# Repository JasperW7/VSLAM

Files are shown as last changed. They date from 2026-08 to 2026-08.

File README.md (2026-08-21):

## For HackClub Macondo
*This repo is forked off of the official FTC SDK & Pedro Pathing

*Heavy inspiration from https://learnopencv.com/monocular-slam-in-python/
### Monocular VSLAM Turret
I was slightly involved in a project a while back focusing on drones and the use of camera vision for mapping over something like a laser used for rangefinding. I got interested in the idea of visual simultaneous localization & mapping (VSLAM) and how it could be integrated into drone navigation systems. My vision for this project was to mainly test out the system flow & software behind a single camera VSLAM (monocular), less so about the automation and navigation. Another challenge I wanted to tackle was configuring monocular VSLAM using a cheap and affordable webcam with low processing power.

### Finished product
Currently, the product is able to use OpenCV to return a camera stream back to Panels stream for viewing, as well as displaying the bot's pose in field coordinates (also viewable under Panels Field).
### Build
All STL Files can be found under [STL Folder](https://github.com/JasperW7/VSLAM/tree/main/STL) with a viewable [Onshape](https://cad.onshape.com/documents/fbfda43b3c9a34854064ec10/w/3fedeb5aa6c3b0ad226559e0/e/34f30c8dd9f021da3e9b9f1b)
You will need:
- wheel x2
- frame x1
- camera holder x1
- gears (2) x1
- pulleys (2) x1
  
The build was designed mainly around M3 screws, and the control system revolves around a [Rev Control Hub](https://www.revrobotics.com/rev-31-1595/), 12V battery (xt30 end), 4 standard 25T PWM servos, 25T servo horns, 64T belt, and a [C270 Logitech webcam]( https://www.logitech.com/en-ca/shop/p/c270-hd-webcam).
For the sake of time, we printed our own [688 bearings](https://grabcad.com/library/688-bearing-8x16x5mm-1), however metal 688 bearings will work as well.

For assembly, simply attach the servos to the frame & gears with screws, then mount the wheels after. This avoids the wheels from blocking the screw mounting for the servos. 
Next, attach the bearings into the frame and big gear holders (we used super glue). You can attach the big gear to the frame and the camera holder into the holders now. Attach the pulley to the tilt servo with a belt running across the pulleys.
Finally, remove the stock c270 mount from the webcam and slide the isolated webcam into the camera holder.
Wire the servos to ports 0,1,2, and 3, plug in the webcam usb to the USB port on the control hub and connect the battery to power it up. [Wiring Diagram](https://github.com/JasperW7/VSLAM/blob/main/Wiring%20Diagram.png)


### Software
To get started with software, simply install Android Studio and clone this repository. To upload this repository onto the control hub, simply connect a usb c to the control hub port and click on the "Run TeamCode" button. Another option is to install the ADB Wifi plugin and connect to the control hub wifi to push code. 

To access the Panels Dashboard, connect to the robot wifi and head to http://192.168.43.1:8001/ on your browser. For setup, under the Teleop dropdown, select the calibration opmode. You will need to print out the following checkerboard pattern used for OpenCV's checkerboard calibration: https://github.com/opencv/opencv/blob/4.x/doc/pattern.png. Run the opmode and select widgets under the Panels Dashboard for Camera Stream. Ensure that the webcam is able to see the checkerboard and move the camera around (you can use the pan and tilt servos for this or you can move the camera manually). The calibration will select 20 points and return calibration values (fx, fy, etc.) to telemetry. Hold onto these values.

Finally, you can run the "test vslam" opmode. Under configurable variables, plug in the fx, fy, cx, cy, k1, etc. calibrated values. The defaults in there are the values that worked for me. Under Panel's camera stream, there should be points plotted by OpenCV's ORB feature extraction. For mapping, simply add a widget for the Panels Field. On top of the field drawing, there will be lines displayed for the camera's pose.
 
___
## Day-by-day journal entries (Failures, Thoughts, etc.) [https://docs.google.com/document/d/1HC7wofTFJbAAgc9IIZ6yAzwW5cy-wWwRABX2THkkn_8/edit?tab=t.0]

Aug 2

Our vision for this project is to learn and utilize Visual Simultaneous Localization & Mapping (VSLAM) using a single cheap and affordable webcam. Our goal is to have a fully autonomous 2 degree of freedom camera scan the full area in 3-d space and map out the environment accurately. 

Today, we focused on planning out our design and taking inventory of the parts we had available. For our project, we wanted to incorporate multiple subsystems that worked together, namely a 2-wheel drive base, a 2DOF turret and a camera. 

In our first sketch, we discussed how our robot would behave in the environment. For example, our initial idea was to only include a panning turret, however we decided that we wanted to have a robot that was able to drive around and a secondary tilt in addition to the panning. We drew rough ideas of how these mechanisms would interact with each other, such as the tilt servo driving a belt that controls the shaft that the camera is mounted onto.

After our rough draft, we spent some time detailing our drawing to define the major parts of the build. Notably this includes the implementation of our servos and how we plan for them to provide the 2 axis of rotation. This allows us to more thoroughly visualize the project before we begin our CAD.

Aug 2 

With a general idea of the direction we were headed, we began CADing on OnShape. While I (Jasper) imported the CAD of the REV servo and generated the gears, Bowen began modeling the servo mount/frame. 

We wanted as many parts of our robot to be as 3d-printable as possible, however, one issue we encountered was the possibility of printing servo horns. Since the spline was too fine, we opted for buying aluminum horns. One issue we faced was finding online STL/Step files that were available to match the online listings so that we could accurately place them into our CAD. We worried that if a cad didn’t match, parts wouldn’t mesh properly. Eventually, we found a proper step file and based all of the servo attachments such as the wheels and gears off of it.

Designing the servo mount was relatively smooth as it was just the projection of the servos’ outline to create holes. 2 mounts were created vertically for the wheels and one was created horizontally on the surface of the mount for the camera’s panning. We had to tweak the positioning of the servo as initially we wished for the servo to be placed vertically (shown in the following picture), though it ended up taking too much space. This was not a difficult change fortunately as we just rolled back a couple edits and recreated the necessary holes.

Another issue we forgot to account for was the existence of the control system. We forgot to incorporate the control hub and battery into our original sketch, and since we wanted the profile of the robot to be as small as possible, another challenge was fitting the control system in without taking up too much space. We found that the space between the wheel servos was enough to fit the control hub and we could still attach the battery underneath as long as we extended the frame. We intend to add a balancing ball at the bottom to keep the battery from touching the ground. 

Aug 3 

With the foundation of the bot finished, today we aim to model the camera mount and the pulley system that will control the camera’s tilt. Going off of our sketch, we had a few major parts to CAD. The large gear has to be modified with handles that support the shaft and pulley system (Jasper). A hex shaft also has to be made with an integrated mount which will ultimately hold the camera (Bowen).

Handles

The handles were relatively smooth to CAD. Just 2 extrusions on the gear with a rounded top so the camera clears it when looking up and down. Going into this project, we wanted to create this robot without the need for funding by using spare parts we already own. Jasper already has a pulley system of 2 gears and a belt (we may just union the gear on the shaft to the shaft itself to print as one part, but we’ll consider that later). The belt he has is 64 teeth, which caused some issues in the modeling of the handles as we needed to continually increase the height of them to accommodate for its length. This was also necessary as the camera must sit high enough to capture the floor in its FOV without being blocked by the chassis. Additionally, a slot for our fourth and final servo that will be spinning the servo.

Shaft/Camera Mount

The shaft went through a couple iterations in its design as the cameras’ hinges and dimensions were a tad finicky. I (Bowen) initially created the shaft to be a cylinder rather than a hex shaft. This was not very practical as there needs to be as much friction as possible for it to move with the bearing. 

We are using a logitech camera that has this mounting hole on the back:

So I initially designed the axle to have a horn that threads through the hole to support the camera vertically (1).  This small horn was very brittle and would’ve likely snapped due to the weight of the camera or the motion of the pulley. As such, I added a back to the horn that would help to hold up the camera. While I was designing this, it was about the time when Jasper imported the CAD for his pulley and mated it onto our existing model. It was then that I noticed the camera indeed clipped into the pulley as I didn’t expect the pulley to be so large (2). This is why we ended up rotating the camera, placing it horizontally to help it clear the pulley. I then restarted the design for my axle to account for this, making sure the lens itself was still centered and the camera protruded enough to clear the pulley (3).

Since most of the CAD was near completion, we decided to go through and check if there were any failure points that could occur, including checking how wires would route and fasteners. 

We decided to perform voronoi pocketing on the frame to create holes where we could zip tie extra lengths of wire so they wouldn’t drag on the ground. This came with the extra benefit of aesthetics as well while not being damaging to structural integrity. 

Another problem we realized was that the servo we were using for panning the gears was blocking the USB port on the control hub, meaning the camera wouldn’t be able to connect to the control system. Because of this, we rotated the servo around the spline 180 degrees to instead block the HDMI port. We also added in the balancing ball point underneath the battery box to hold it up against the ground. We figured that a point round surface scraping the ground would be better than an entire flat surface against the ground. 

Finally, after much review, we sent the necessary CAD pieces off to print (while we go out to buy fasteners). 

We also started looking into an article about the algorithm behind monocular VSLAM and understanding how it works, previewing ourselves for when we get into the software side.

We looked inside multiple hardware stores for M3 screws but couldn’t find any. Nonetheless, we decided to first stop and test the controller we would use to control the robot. We wanted to test the controllers connection to the driver station APK and ensure that it would work. 

One issue we found was that we couldn’t directly connect the controller straight to the phone with a usb c to c wire. For connections, the controller would only return values through a usb A wire. Therefore, we bought an adapter to go from usb c to usb a to usb c :). This worked :).

We picked up the parts for our control system including the control hub, adapter wire and logitech c270 webcam that we would be using. (We were also going to pickup our CAD prints too but the print layer shifted so we restarted the print). 

One thing we noticed when we tested the battery to wire converter to control hub power was the connection was iffy. If the wire was bent the wrong way, the power would disconnect. Seeing as the power had to go through a tamiya connector and then to an xt30 connector, we imagined that the tamiya connection was a potential failure point. So, we cut off the tamiya connection and soldered the xt30 head straight to the wire.

While soldering, we had trouble getting the solder wire to flow through the wire. We thought flux would allow it to flow better, but even with flux, the solder wire just wouldn’t flow. This is when we realized that better solder wire is more advantageous than just good flux alone. The solder wire we got was bought cheap online, which explains why it wouldn’t flow properly. Even so, after soldering, our wire passed the pull test so we figured it would hold up. 

We tested it by connecting it to the control hub and it wouldn’t power on. We thought it was a soldering mistake again so we re-soldered the joint. After the second attempt was finished, it still wouldn’t power on. This is when we realized that the fuse that is inside the battery wire had been blown out. Once we swapped the fuse, it powered up.

## **Assembly**

Though the battery can connect to the control hub, we forgot the charging wire connected through the tamiya head. As such, we had to spend some time soldering an adapter that connects the battery’s xt30 back to the tamiya to be able to charge.

### Bearings
As the prints were finished we began to assemble the chassis. We ran into a couple issues with the bearings and the shafts they were supposed to hold. It seems that the tolerance for the shaft was incorrectly done. It took a lot of force to get the shaft into the bearing. In doing so we broke the axle under the big gear.

After it superglues back on, we’ll sand or file it down so it cleanly fits into the bearing. The camera shaft has a similar issue, but we got it in eventually. All the holes for the bearings were a bit too large and made them loose, though it's not much of an issue as we can use superglue to keep them in place.

## Camera Mount
The shaft that holds the camera also did not fit the camera in real life. More specifically the backing that was supposed to hold the camera ended up being so long that the rod in the middle could not be threaded into the hole in the middle. We had to cut off a bit of the edge which allowed the camera to fit.



## Battery holder
A similar thing happened with the battery holder. The battery was bigger in real life, so we just cut off a side of the holder to help it squeeze in.



## Pulley Installation of Doom
There were many issues with the pulley installation. Aside from the bearings not fitting the shaft perfectly, we forgot to put the belt in before we put the axle on. So we had to remove the already stuck and glued bearings and put the belt in. Then we realised the shaft itself was put on the wrong way (not on the side of the servo), so we had to take everything off AGAIN and flip it. Yikes!

The screws we used to connect the wheels to the servo were too long, so we cut them to size.



## Axle on the Big Gear
Back to the axle on the big gear that snapped off when we tried forcing the bearing in. The superglue was taking a while to dry, so we put a bit of water around it. For some reason it turned white and still didn’t dry. Not sure how we’re going to deal with this but I hope it’ll just dry eventually.



Here's some final pictures of our progress today:


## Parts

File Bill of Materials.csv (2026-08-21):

Type | Link | Part number/SKU | Item | Quantity | Price
3d print | N/A | N/A | Frame | 1 | $0
3d print | N/A | N/A | Small gear | 1 | $0
3d print | N/A | N/A | Big gear | 1 | $0
3d print | N/A | N/A | Pulley | 1 | $0
3d print | N/A | N/A | Camera holder | 1 | $0
3d print | N/A | N/A | Wheel | 2 | $0
3d print | N/A | N/A | 688 bearings | 3 | $0
Control system | https://revrobotics.ca/rev-31-1595/ | REV-31-1595 | Control hub | 1 | $525.00
Control system | https://www.studica.ca/en/txm-12-volt-rechargeable-nimh-battery-pack | 39057 | Battery | 1 | $92.00
Control system | https://www.studica.ca/en/xt30-mh-fc-to-tamiya-mh-fc-cable | 70179 | Tamiya to XT30 adapter | 1 | $5.73
Control system | https://revrobotics.ca/rev-41-1097/ | REV-41-1097 | Servo | 4 | $34.42
Control system | https://www.amazon.ca/Logitech-Widescreen-Calling-Recording-960-000694/dp/B004FHO5Y6?th=1 |  | Logitech C270 webcam | 1 | $27.96
Control system | https://www.gobilda.com/3412-series-5mm-htd-pitch-timing-belt-9mm-width-320mm-pitch-length-64-tooth/ | 3412-0009-0320 | 64T HTD5 belt | 1 | $7.56
Fastener | https://www.amazon.ca/Kozelo-440pcs-Socket-Screws-Assortment/dp/B0DK5ZMMY6 |  | M3 screw 30mm | 4 | $24.79
Fastener |  |  | M3 screw 20mm | 8
Fastener |  |  | M4 screw 12mm | 8
Fastener |  |  | M3 nyloc nut | 6
Fastener |  |  | M4 nyloc nut | 8
Fastener | https://www.amazon.ca/dp/B0F5QDX7PN?ref=ppx_yo2ov_dt_b_fed_asin_title |  | 25T servo horn | 4 | $12.99

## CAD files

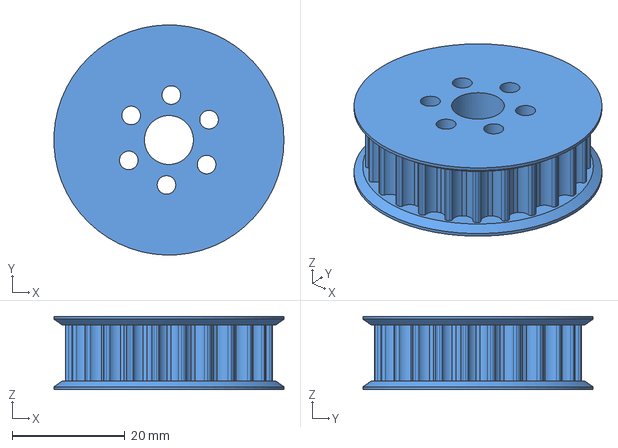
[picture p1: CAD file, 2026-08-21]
CAD/STEP/Assembly 1 - [LS] Pulley HTD5 24T.step
40.9 x 40.9 x 13.0 mm

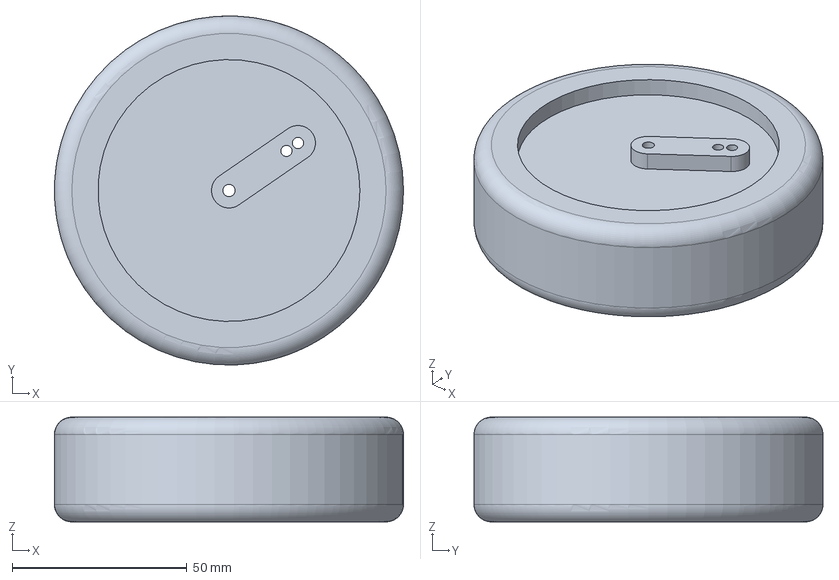
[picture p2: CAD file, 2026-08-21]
CAD/STEP/Assembly 1 - wheel.step
100.0 x 100.0 x 30.0 mm

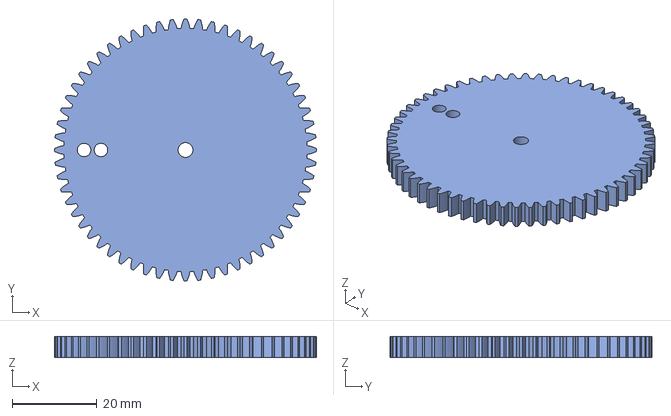
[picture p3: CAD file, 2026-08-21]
CAD/STEP/Assembly 1 - Spur 1M 60T.step
62.0 x 62.0 x 5.00 mm

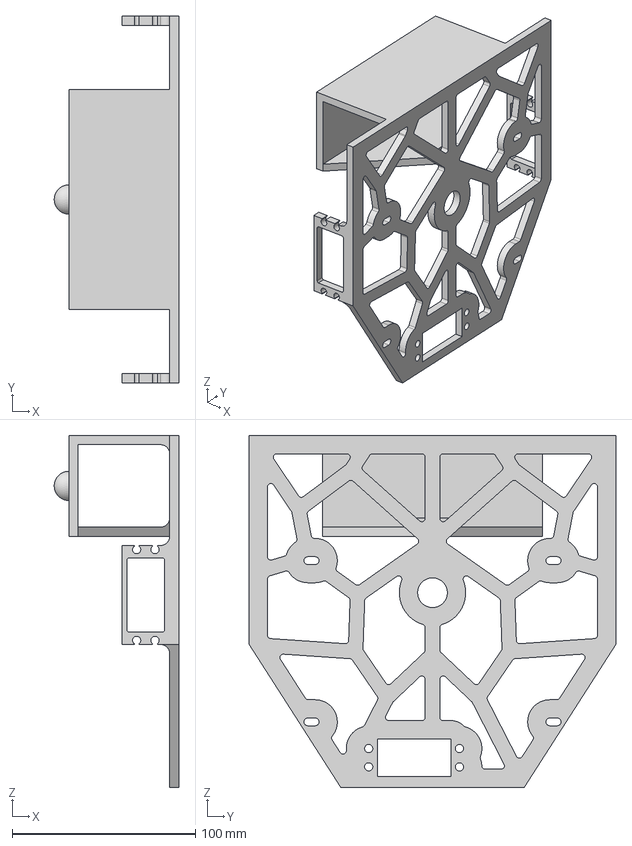
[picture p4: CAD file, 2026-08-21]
CAD/STEP/Assembly 1 - frame.step
68.0 x 200.0 x 192.0 mm

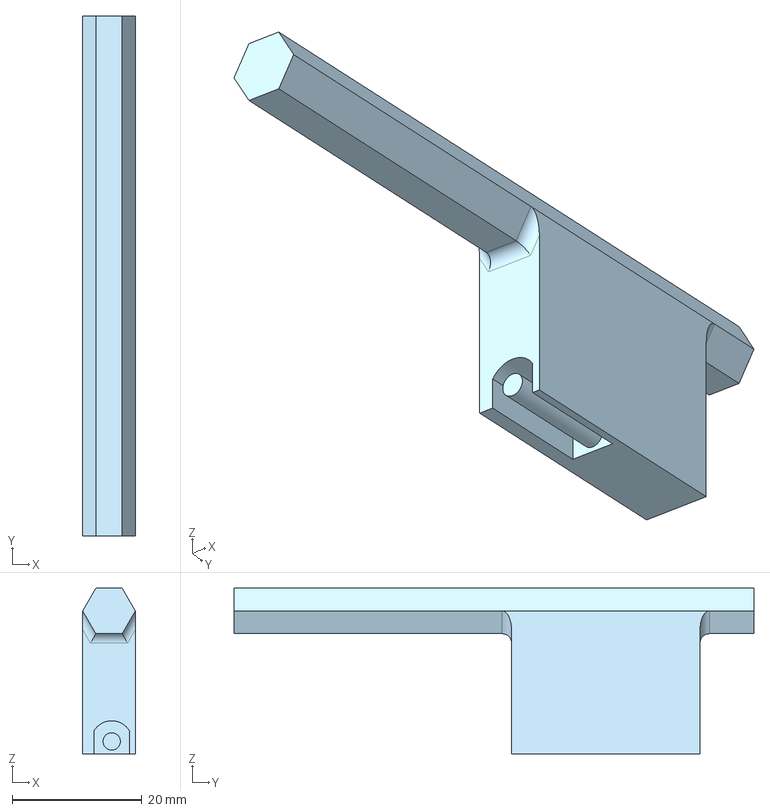
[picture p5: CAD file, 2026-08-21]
CAD/STEP/Assembly 1 - camera holder.step
8.10 x 80.0 x 25.5 mm

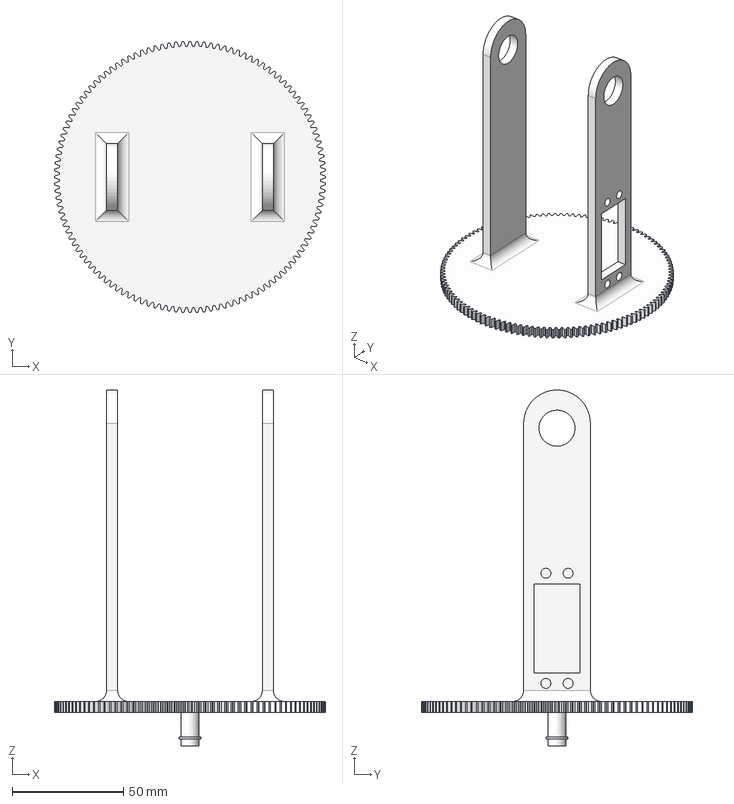
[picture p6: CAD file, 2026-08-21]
CAD/STEP/Assembly 1 - Spur 1M 120T.step
122.0 x 122.0 x 160.0 mm

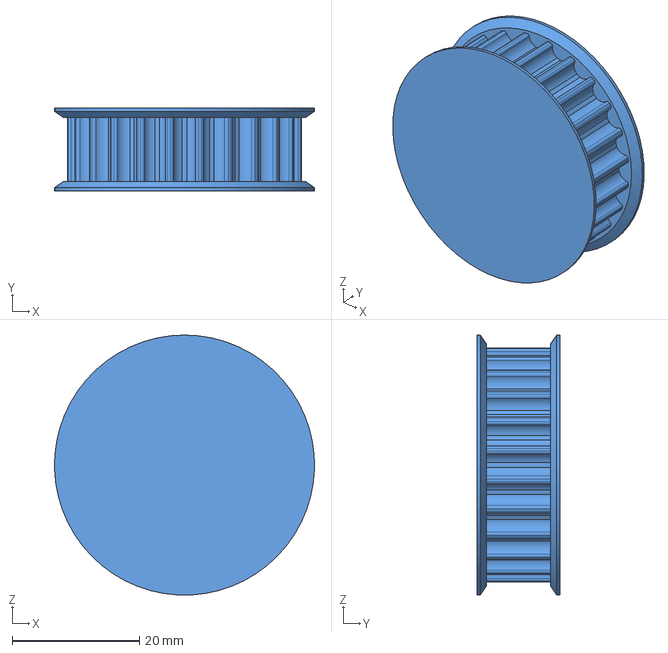
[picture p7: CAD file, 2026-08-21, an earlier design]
CAD/STEP/Assembly 1 - [LS] Pulley HTD5 24T (1).step
40.9 x 13.0 x 40.9 mm

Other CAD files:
CAD/STL/Assembly 1 - Spur 1M 120T.stl
CAD/STL/Assembly 1 - Spur 1M 60T.stl
CAD/STL/Assembly 1 - [LS] Pulley HTD5 24T (1).stl
CAD/STL/Assembly 1 - [LS] Pulley HTD5 24T.stl
CAD/STL/Assembly 1 - camera holder.stl
CAD/STL/Assembly 1 - frame.stl
CAD/STL/Assembly 1 - wheel.stl

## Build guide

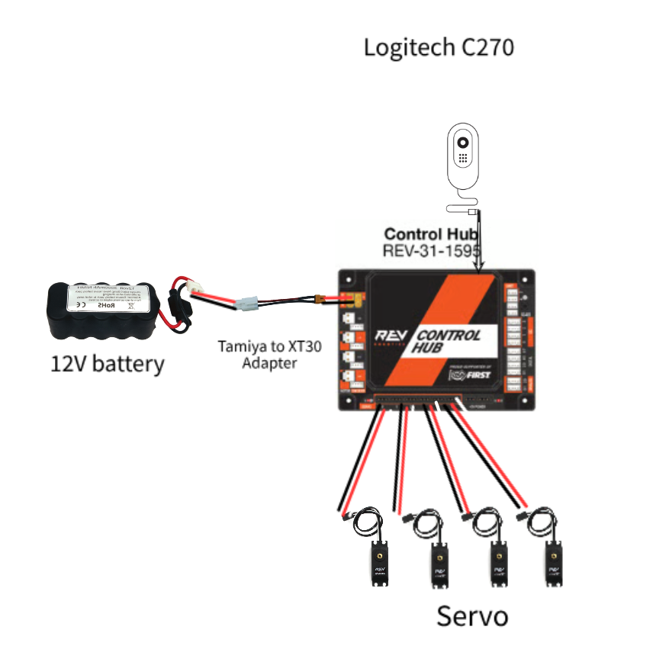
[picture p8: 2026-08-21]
Wiring Diagram.png

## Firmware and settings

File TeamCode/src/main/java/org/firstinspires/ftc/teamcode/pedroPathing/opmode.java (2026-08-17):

package org.firstinspires.ftc.teamcode.pedroPathing;

import android.graphics.Bitmap;
import android.graphics.Canvas;

import com.acmerobotics.dashboard.config.Config;
import com.bylazar.camerastream.PanelsCameraStream;
import com.bylazar.configurables.annotations.Configurable;
import com.bylazar.telemetry.PanelsTelemetry;
import com.bylazar.telemetry.TelemetryManager;
import com.qualcomm.robotcore.eventloop.opmode.OpMode;
import com.qualcomm.robotcore.eventloop.opmode.TeleOp;
import com.qualcomm.robotcore.hardware.Servo;

import org.firstinspires.ftc.robotcore.external.function.Consumer;
import org.firstinspires.ftc.robotcore.external.function.Continuation;
import org.firstinspires.ftc.robotcore.external.hardware.camera.Camera;
import org.firstinspires.ftc.robotcore.external.hardware.camera.WebcamName;
import org.firstinspires.ftc.robotcore.external.stream.CameraStreamSource;
import org.opencv.core.Point;
import org.opencv.core.Scalar;
import org.opencv.imgproc.Imgproc;
import org.openftc.easyopencv.OpenCvCamera;
import org.openftc.easyopencv.OpenCvCameraFactory;
import org.openftc.easyopencv.OpenCvCameraRotation;
import org.openftc.easyopencv.OpenCvPipeline;
import org.opencv.android.Utils;
import org.opencv.core.Mat;
import org.opencv.core.MatOfPoint2f;
import org.opencv.core.MatOfPoint3f;
import org.opencv.core.MatOfDMatch;
import org.opencv.core.DMatch;
import org.opencv.core.CvType;
import org.opencv.calib3d.Calib3d;
import java.util.ArrayList;
import java.util.List;
import java.util.concurrent.atomic.AtomicReference;
@Configurable
@TeleOp(name="VSLAM")
public class opmode extends OpMode {
    Servo wheel1,wheel2,pan,tilt;
    OpenCvCamera webcam;
    TelemetryManager.TelemetryWrapper panelsTelemetry;
    CameraStreamSource source;
    public static double wheel1Pos=0.5,wheel2Pos=0.5,panPos=0.5,tiltPos=0.3;
    public static double brightnessTolerance = 0.2;
    public static int consecutiveBrightnessTol = 11;
    public static double matchRatio = 0.7;
    public static int maxDescriptorDistance = 2500;
    public static int ransacInt = 30;
    public static double ransacThresh = 5;

    public static ArrayList<Feature> features = new ArrayList<>();
    public static ArrayList<Match> matches = new ArrayList<>();
    @Override
    public void init() {
        wheel1 = hardwareMap.get(Servo.class,"wheel1");
        wheel2 = hardwareMap.get(Servo.class,"wheel2");
        pan = hardwareMap.get(Servo.class,"pan");
        tilt = hardwareMap.get(Servo.class,"tilt");
        panelsTelemetry = PanelsTelemetry.INSTANCE.getFtcTelemetry();

        int cameraMonitorViewId = hardwareMap.appContext.getResources().getIdentifier("cameraMonitorViewId","id",hardwareMap.appContext.getPackageName());
        WebcamName webcamName = hardwareMap.get(WebcamName.class,"c270");
        webcam = OpenCvCameraFactory.getInstance().createWebcam(webcamName,cameraMonitorViewId);
        CameraPipeline pipeline = new CameraPipeline();

        webcam.setPipeline(pipeline);
        source = pipeline;

        webcam.openCameraDeviceAsync(
                new OpenCvCamera.AsyncCameraOpenListener() {
                    @Override
                    public void onOpened() {
                        webcam.startStreaming(
                                640,480, OpenCvCameraRotation.UPRIGHT
                        );

                        PanelsCameraStream.INSTANCE.startStream(source,60);
                        panelsTelemetry.addData("Camera:", "Opened");
                        panelsTelemetry.update();

                    }

                    @Override
                    public void onError(int errorCode) {
                        panelsTelemetry.addData("Error: ",errorCode);
                        panelsTelemetry.update();
                    }
                }
        );
    }


    @Override
    public void init_loop(){
        wheel1.setPosition(wheel1Pos);
        wheel2.setPosition(wheel2Pos);
        tilt.setPosition(tiltPos);
        pan.setPosition(panPos);

        panelsTelemetry.addData("Status: ","Init");
        panelsTelemetry.update();
    }

    @Override
    public void start(){

    }

    @Override
    public void loop() {
        wheel1.setPosition(wheel1Pos);
        wheel2.setPosition(wheel2Pos);
        tilt.setPosition(tiltPos);
        pan.setPosition(panPos);

        panelsTelemetry.addData("feature count: ", features.size());
        panelsTelemetry.addData("matches: ", matches.size());
        panelsTelemetry.addData("fps",webcam.getFps());
        panelsTelemetry.addData("camera: ", "running");
        panelsTelemetry.update();

    }

    @Override
    public void stop(){
        PanelsCameraStream.INSTANCE.stopStream();
        if (webcam!=null){
            webcam.stopStreaming();
            webcam.closeCameraDevice();
        }
    }



    public static class CameraPipeline extends OpenCvPipeline implements CameraStreamSource {

        private byte[] pixels;
        private final int[][] rad3circle = {
                {0, -3}, //13
                {1, -3}, //14
                {2, -2}, //15
                {3, -1}, //16
                {3, 0}, //1
                {3, 1}, //2
                {2, 2}, //3
                {1, 3}, //4
                {0, 3}, //5
                {-1, 3}, //6
                {-2, 2}, //7
                {-3, 1}, //8
                {-3, 0}, //9
                {-3, -1}, //10
                {-2, -2}, //11
                {-1, -3} //12
        };
        private ArrayList<Feature> previousFeatures = new ArrayList<>();
        private ArrayList<Feature> currentFeatures = new ArrayList<>();
        private final AtomicReference<Bitmap> lastFrame =
                new AtomicReference<>(
                        Bitmap.createBitmap(
                                1, 1, Bitmap.Config.RGB_565
                        )
                );
        private final Mat cameraMat = new Mat(3,3,CvType.CV_64F);
        private final Mat distortionCoeff = new Mat(5,1,CvType.CV_64F);

        public CameraPipeline(){
            cameraMat.put(0,0,1201.301549650407,0,408.86431808728605,0,1183.633514447323,161.5314095319902,0,0,1);
            distortionCoeff.put(0,0,0.46312970087929056,-1.9861524150618615,-0.0041021594732788,0.07755604987483086,4.769011405961361);
        }
        @Override
        public Mat processFrame(Mat input) {
            /**
             * Processing
             */
            Mat undistorted = new Mat();
            Calib3d.undistort(input,undistorted,cameraMat,distortionCoeff);
            Mat gray = new Mat();
            Imgproc.cvtColor(undistorted,gray,Imgproc.COLOR_RGB2GRAY);//undistorted greyscale
            //read through all pixels and obtain brightness of each

            int width = gray.cols();
            int height = gray.rows();
            if (pixels == null || pixels.length != width * height) {
                pixels = new byte[width * height];
            }
            gray.get(0, 0, pixels);
            //feature extraction
            currentFeatures.clear();
            for (int y = 3; y < height - 3; y += 4) {
                for (int x = 3; x < width - 3; x += 4) {
                    if (isFeaturePoint(pixels, width, x, y, consecutiveBrightnessTol)) {
                        Point point = new Point(x, y);
                        byte[] descriptor = createDescriptor(pixels, width, x, y);
                        currentFeatures.add(new Feature(point, descriptor));
//                        input.put(y,x,255);
                    }
                }
            }
            //feature matching
            if (!previousFeatures.isEmpty()) {
                matches = ransacFilter(matchFeatures(previousFeatures, currentFeatures));
            } else {
                matches.clear();
            }
            Mat display = new Mat();
            Imgproc.cvtColor(gray, display, Imgproc.COLOR_GRAY2RGB);

            for (Match match:matches){
                Point previous = match.previous.point;
                Point current = match.current.point;
                Imgproc.circle(display,previous,4,new Scalar(255,0,0),1);
                Imgproc.line(display,previous,current,new Scalar(0,255,255),1);
                Imgproc.circle(display,current,2,new Scalar(255,0,0),-1);
            }
            features.clear();
            features.addAll(currentFeatures);
            previousFeatures = new ArrayList<>(currentFeatures);


            Bitmap bitmap = Bitmap.createBitmap(
                    display.width(),
                    display.height(),
                    Bitmap.Config.RGB_565
            );
            Utils.matToBitmap(display, bitmap);
            lastFrame.set(bitmap);
            undistorted.release();
            gray.release();

            return display;
        }

        @Override
        public void getFrameBitmap(Continuation<? extends Consumer<Bitmap>> continuation) {
            continuation.dispatch(
                    bitmapConsumer ->
                            bitmapConsumer.accept(lastFrame.get())
            );
        }

        public boolean isFeaturePoint(byte[] pixels, int width, int x, int y, int N) {

            int centerIdx = y * width + x;
            int centerBrightness = pixels[centerIdx] & 0xFF;

            int threshold = Math.max(20, (int) (centerBrightness * brightnessTolerance));
            int high = centerBrightness + threshold;
            int low = centerBrightness - threshold;
            //local contrast test
            int min = 255;
            int max = 0;

            for (int i = 0; i < 16; i++) {
                int px = x + rad3circle[i][0];
                int py = y + rad3circle[i][1];
                int value = pixels[py * width + px] & 0xFF;
                if (value > max) {
                    max = value;
                }
                if (value < min) {
                    min = value;
                }
            }
            if (max - min < 40) {
                return false;
            }

            //early rejection test
            int bright = 0, dark = 0;
            int value = pixels[y * width + (x + 3)] & 0xFF;
            if (value > high) {
                bright++;
            } else if (value < low) {
                dark++;
            }
            value = pixels[y * width + (x - 3)] & 0xFF;
            if (value > high) {
                bright++;
            } else if (value < low) {
                dark++;
            }
            value = pixels[(y - 3) * width + x] & 0xFF;
            if (value > high) {
                bright++;
            } else if (value < low) {
                dark++;
            }
            value = pixels[(y + 3) * width + x] & 0xFF;
            if (value > high) {
                bright++;
            } else if (value < low) {
                dark++;
            }

            if (bright < 3 && dark < 3) {
                return false;
            }

            //fast circle test
            int consecB = 0, consecD = 0;
            for (int i = 0; i < 16 + N - 1; i++) {

                int idx = i % 16;
                int px = x + rad3circle[idx][0];
                int py = y + rad3circle[idx][1];
                int pixelIdx = py * width + px;

                double pixelBrightness = pixels[pixelIdx] & 0xFF;

                if (pixelBrightness > centerBrightness + threshold) {
                    consecB++;
                    consecD = 0;
                } else if (pixelBrightness < centerBrightness - threshold) {
                    consecD++;
                    consecB = 0;
                } else {
                    consecB = 0;
                    consecD = 0;
                }

                if (consecD >= N || consecB >= N) {
                    return true;
                }
            }
            return false;
        }

        public byte[] createDescriptor(byte[] pixels, int width, int x, int y) {
            byte[] descriptor = new byte[49];
            int index = 0;
            int sum = 0;
            for (int dy = -3; dy <= 3; dy++) {
                for (int dx = -3; dx <= 3; dx++) {
                    int px = x + dx;
                    int py = y + dy;
                    int val = pixels[py * width + px] & 0xFF;
                    descriptor[index++] = (byte) val;
                    sum += val;
                }
            }
            double average = (double) sum / 49;
            for (int i = 0; i < descriptor.length; i++) {
                int val = descriptor[i] & 0xFF;
                descriptor[i] = (byte) (val - average);
            }
            return descriptor;
        }

        public ArrayList<Match> matchFeatures(ArrayList<Feature> previousFeatures, ArrayList<Feature> currentFeatures) {
            ArrayList<Match> result = new ArrayList<>();
            for (Feature current : currentFeatures) {
                int bestIndex = -1;
                Feature bestFeature = null;
                int bestDistance = Integer.MAX_VALUE;
                int secondBestDistance = Integer.MAX_VALUE;
                for (Feature previous : previousFeatures) {
                    int distance = descriptorDistance(current.descriptor, previous.descriptor);
                    if (distance < bestDistance) {
                        secondBestDistance = bestDistance;
                        bestDistance = distance;
                        bestFeature = previous;
                    } else if (distance < secondBestDistance) {
                        secondBestDistance = distance;
                    }
                }
                if (bestFeature == null) {
                    continue;
                }
                if (bestDistance > maxDescriptorDistance) {
                    continue;
                }
                if (secondBestDistance == Integer.MAX_VALUE) {
                    continue;
                }
                double ratio = (double) bestDistance / (double) secondBestDistance;
                if (ratio < matchRatio) {
                    result.add(new Match(bestFeature, current, bestDistance));
                }
            }
            return result;
        }

        public ArrayList<Match> ransacFilter(ArrayList<Match> input){
            ArrayList<Match> result = new ArrayList<>();
            if (input.isEmpty()){
                return result;
            }
            java.util.Random random = new java.util.Random();
            int best = 0;
            for (int i = 0; i<ransacInt;i++){
                Match sample = input.get(random.nextInt(input.size()));
                double dx = sample.current.point.x-sample.previous.point.x;
                double dy = sample.current.point.y-sample.previous.point.y;
                ArrayList<Match> inliers = new ArrayList<>();
                for (Match match:input){
                    double mDx = match.current.point.x-match.previous.point.x;
                    double mDy = match.current.point.y-match.previous.point.y;
                    double error = Math.hypot(mDx-dx,mDy-dy);
                    if(error<ransacThresh){
                        inliers.add(match);
                    }
                }
                if(inliers.size()>best){
                    best = inliers.size();
                    result = inliers;
                }
            }
            return result;
        }
        public int descriptorDistance(byte[] a, byte[] b) {
            int distance = 0;
            for (int i = 0; i < a.length; i++) {
                int valueA = a[i];
                int valueB = b[i];
                distance += Math.abs(valueA - valueB);
            }
            return distance;
        }
    }

    public static class Feature{
        public Point point;
        public byte[] descriptor;
        public Feature(Point point, byte[] descriptor){
            this.point = point;
            this.descriptor=descriptor;
        }
    }

    public static class Match{
        public Feature previous;
        public Feature current;
        public int distance;
        public Match(Feature previous, Feature current, int distance){
            this.previous = previous;
            this.current=current;
            this.distance=distance;

        }
    }

}

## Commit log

2026-08-11 camera stream test
2026-08-11 camera stream testt
2026-08-13 frame matching
2026-08-14 ransac filter
2026-08-20 Create STL folder
2026-08-20 Add Onshape link to STL file
2026-08-20 Clarify required parts with quantities for gears and pulleys
    Updated the list of required parts to specify quantities for gears and pulleys.
2026-08-20 Update README with Panels Dashboard and calibration steps
    Added instructions for accessing the Panels Dashboard and performing camera calibration.
2026-08-21 Update README with wiring diagram link
    Added a link to the wiring diagram for clarity.
